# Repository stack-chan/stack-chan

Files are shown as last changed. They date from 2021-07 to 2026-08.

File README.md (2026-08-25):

# Stack-chan




[日本語](./README_ja.md)

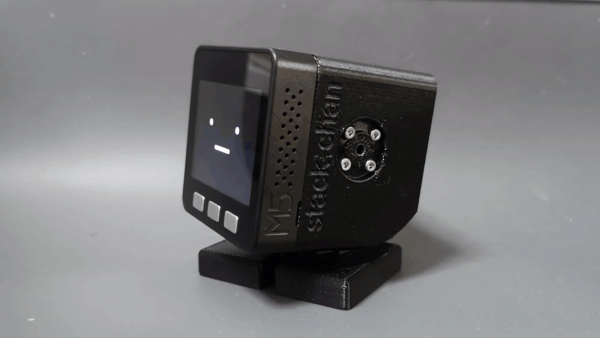
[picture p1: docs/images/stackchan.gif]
stackchan


Stack-chan is an open-source, JavaScript-driven, super-kawaii robot built with M5Stack.

This repository provides firmware with M5StackChan CoreS3 as its standard configuration, user applications called MODs, browser development tools, cases, and schematics.

- Video (with English subtitles): https://youtu.be/fZb_mF08xV0
- Official hashtag: [`#stackchan` | `#ｽﾀｯｸﾁｬﾝ` (JP)](https://twitter.com/search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)

## Getting started

If this is your first Stack-chan, start with a preassembled M5StackChan and the browser tools.

### 1. Get an M5StackChan

The standard M5StackChan AI Desktop Robot (K151) package is enough to get started.
The joystick remote controller is optional.

- Worldwide: [M5Stack Official Store](https://shop.m5stack.com/products/stackchan-kawaii-co-created-open-source-ai-desktop-robot)
- Japan: [M5StackChan](https://ssci.to/11129)
- Japan: [M5StackChan with joystick remote controller](https://ssci.to/11131)

### 2. Flash the firmware

Connect M5StackChan to a computer with a data-capable USB cable, then open the [Web firmware installer](https://stack-chan.github.io/stack-chan/web/flash/) in Chrome or Edge.
Select "M5StackChan CoreS3" as the device.
You do not need to install the Moddable SDK or ESP-IDF.

> [!IMPORTANT]
> Flashing this repository's firmware replaces the factory firmware supplied by M5Stack.
> To restore it, follow the restore procedure in the [M5Stack product documentation](https://docs.m5stack.com/en/StackChan) and use M5Burner.

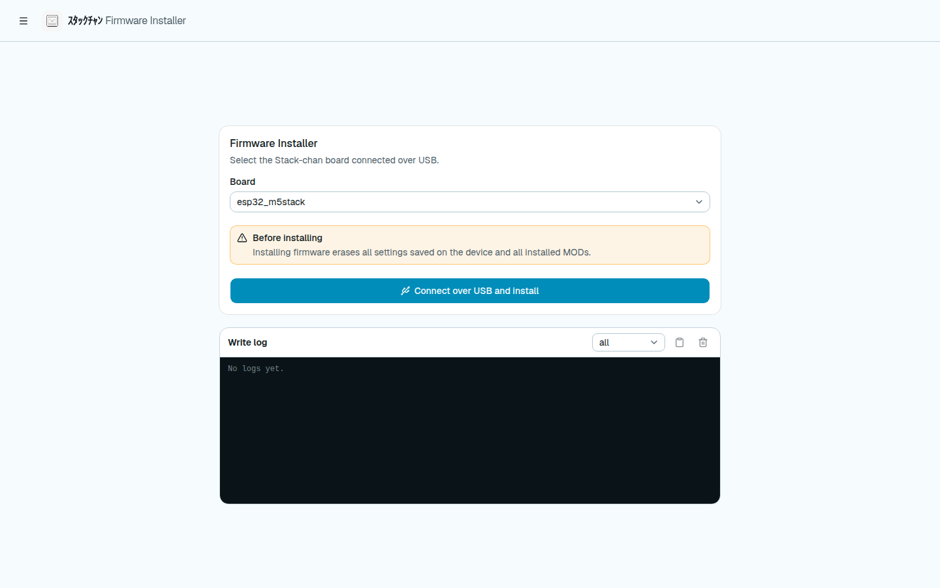
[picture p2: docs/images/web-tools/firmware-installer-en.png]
Web firmware installer


### 3. Try a MOD

Find published MODs and mini apps in the [MOD Gallery](https://stack-chan.github.io/stack-chan/web/mod-gallery/).
Choose a MOD, then run it in the simulator or install it on a device.
Block-based samples can be opened directly in the block editor and changed.

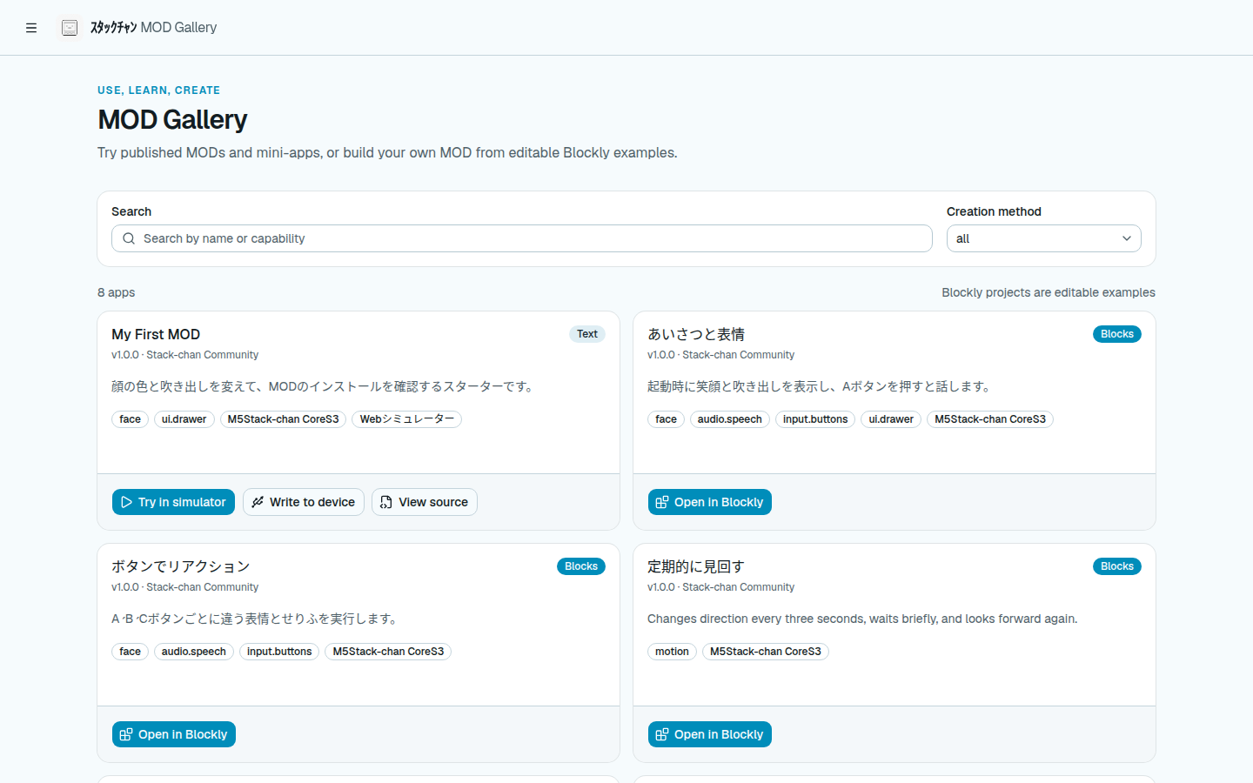
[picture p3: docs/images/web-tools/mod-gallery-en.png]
MOD Gallery


## Browser tools

Use the [Stack-chan browser tools](https://stack-chan.github.io/stack-chan/web/) to set up a device, change its preferences, and create MODs in a browser.

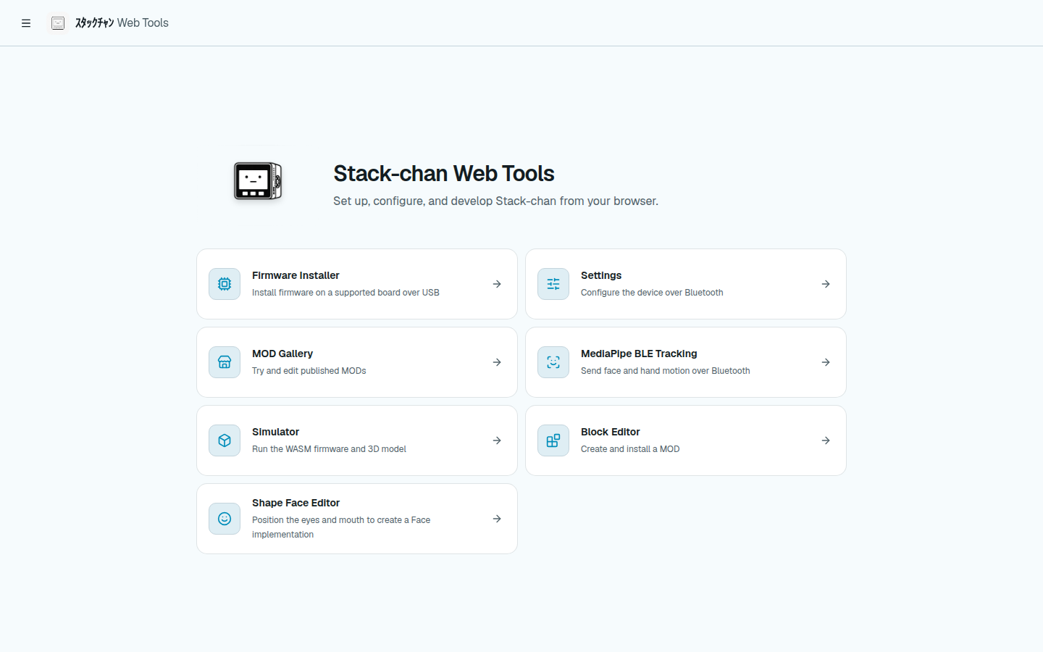
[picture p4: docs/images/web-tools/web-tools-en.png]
Stack-chan browser tools home screen


| Tool | Purpose |
| --- | --- |
| [Firmware installer](https://stack-chan.github.io/stack-chan/web/flash/) | Flash firmware to a supported M5Stack over USB |
| [Preferences](https://stack-chan.github.io/stack-chan/web/preference/) | Change Wi-Fi and device preferences over BLE |
| [MOD Gallery](https://stack-chan.github.io/stack-chan/web/mod-gallery/) | Find, try, and install published MODs |
| [Block editor](https://stack-chan.github.io/stack-chan/web/editor/) | Create MODs with Blockly and run them in the simulator or on a device |
| [Shape face editor](https://stack-chan.github.io/stack-chan/web/face-editor/) | Arrange eyes and a mouth to create a custom Face |
| [Simulator](https://stack-chan.github.io/stack-chan/web/simulator/) | Run MODs with the WebAssembly firmware and a 3D model |
| [MediaPipe BLE tracking](https://stack-chan.github.io/stack-chan/web/mediapipe/) | Send tracked face and hand movement over BLE |

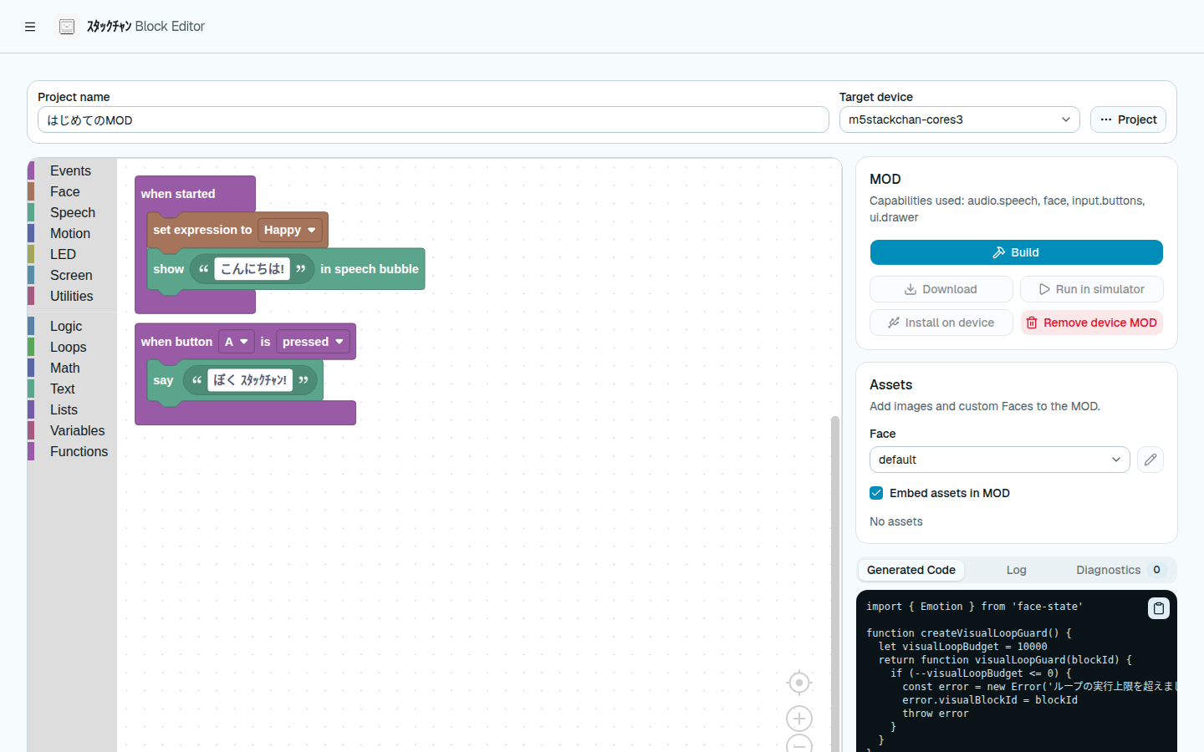
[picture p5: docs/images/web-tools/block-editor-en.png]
Block editor


## Supported hardware

The distributed firmware supports M5Stack, M5Stack Core2, M5Stack CoreS3, and M5StackChan CoreS3.
M5StackChan CoreS3 is the standard configuration and the target used for physical-device release validation.

Firmware for Stack-chan RT and Takao Core2 + SG90 can be built from source.
See the [firmware guide](./firmware/README.md) for target-specific commands and constraints.

To build the hardware yourself, see the [case guide](./case/README.md) for parts and assembly instructions.
See the [schematics](./schematics/README.md) for board information.

## Repository contents

- [firmware](./firmware/): Host firmware, modules, MODs, and development scripts
- [web](./web/): Firmware installer, preferences, editors, Gallery, and simulator
- [case](./case/): Case models for 3D printing
- [schematics](./schematics/): Schematics and board layouts
- [docs](./docs/): Roadmap, specifications, operations guides, and release notes

## Development

- [Firmware development](./firmware/README.md)
- [MOD development](./firmware/mods/README.md)
- [Firmware API](./firmware/docs/api.md)
- [Contribution guide](./CONTRIBUTING.md)
- [Latest release](https://github.com/stack-chan/stack-chan/releases/latest)
- [Development roadmap](./docs/ROADMAP.md)

## Contributing

Feature requests, bug reports, and pull requests are welcome.
Read the [contribution guide](./CONTRIBUTING.md), or open an [issue](https://github.com/stack-chan/stack-chan/issues).

To support the project financially, visit the [GitHub Sponsors page](https://github.com/sponsors/meganetaaan/).

## License

The resources in this repository are distributed under the Apache License 2.0.
See [LICENSE](./LICENSE).

## BibTeX

```bibtex
@misc{stackchan,
  author       = {Shinya Ishikawa and the Stack-chan community},
  title        = {Stack-chan: A JavaScript-driven Super-kawaii Robot},
  year         = {2021},
  howpublished = {\url{https://github.com/stack-chan/stack-chan}},
  note         = {Open-source hardware and software.},
}
```

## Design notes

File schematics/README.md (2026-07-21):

# Stack-chan schematics

[日本語](./README_ja.md)

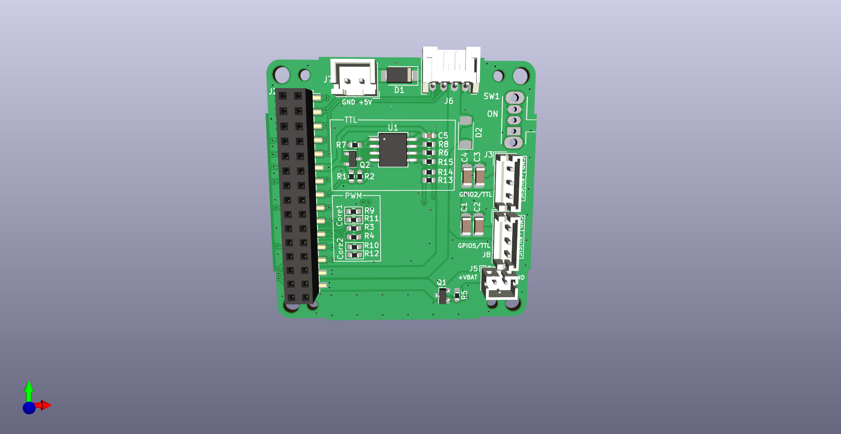
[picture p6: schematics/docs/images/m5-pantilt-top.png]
board top

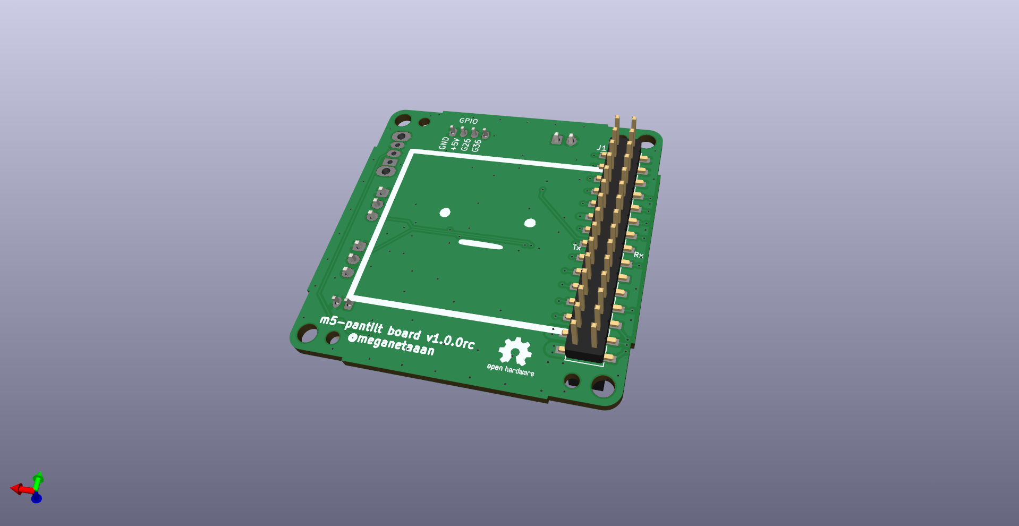
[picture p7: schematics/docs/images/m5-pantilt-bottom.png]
board bottom

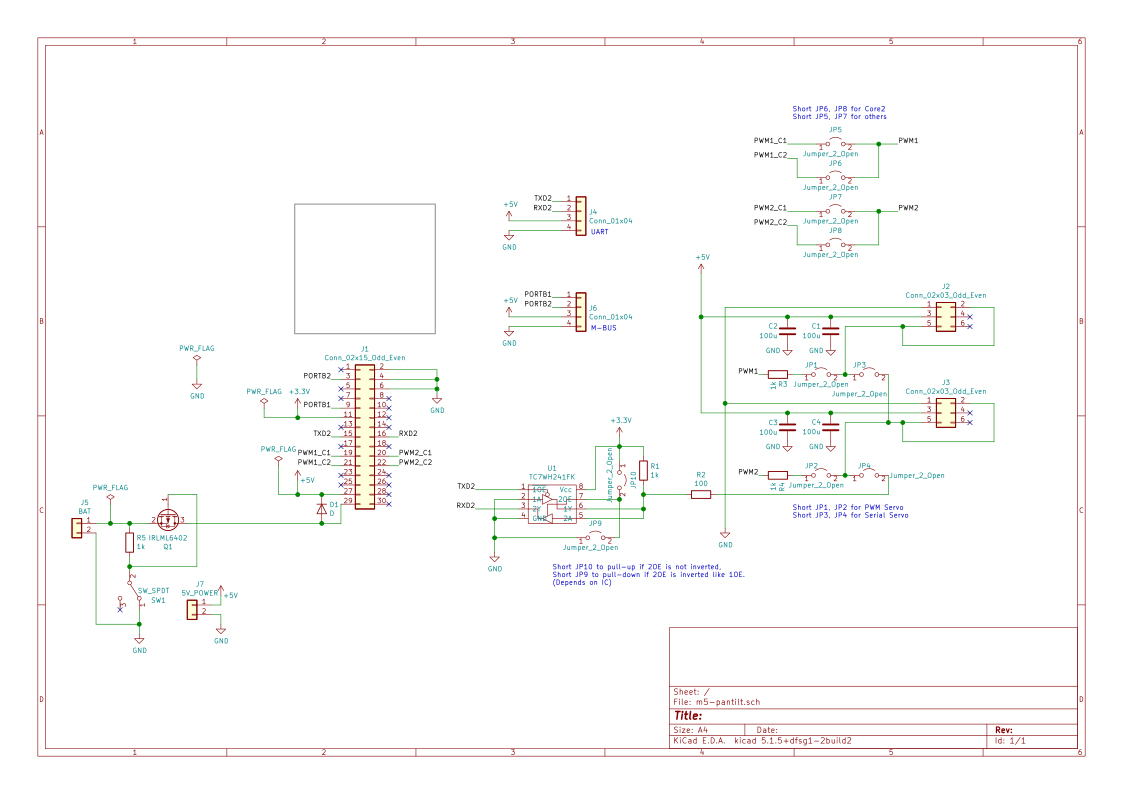
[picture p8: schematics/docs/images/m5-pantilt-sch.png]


## Feature

* Drive two servos
  * PWM * 2ch or
  * Serial * 2ch
* M5Unit PortB
* External 5V Power Supply
* Battery, which can be charged through M5Stack.
* (Optional) Power switch

## Parts list

See the parts list on our GitHub Pages (under construction)

### Which type of servo should I use?

#### PWM (SG90)

**Pros**: Low cost
* Very low cost (~500yen), easy to find.
* PortC (serial communication) is available for users.

**Cons**: Difficult to control and having a (small) safety risk.
* Difficult to change its angle smoothly.
* Inrush current is high and may cause the M5Stack to power down in rare cases. SG90 possibly get very hot and may emit smoke when overloaded, such as when the angle exceeds the physical limits of the Stack-chan.
* Cannot control torque ON/OFF. Twisting the Stack-chan's head while the torque is ON may result in servo damage.

#### Serial (RS304MD)

**Pros**: High functionality
* Complex control such as speed limit is possible. Since the current servo angle can be read, we can make rich functions such as changing the action according to the direction of the stuck-chan's face.

**Cons**: High cost and having a bit large size.
* It is relatively expensive (~3,000 yen)
* Users cannot use PortC. 
* Because RS304MD is a bit larger than SG90, it sticks out slightly behind the body.

## SMD PCB Manufacturing

You can place an order for SMD (Surface Mount Device) PCBs with PCB manufacturers like JLCPCB using the following files (links to be added):

- Gerber Files
- BOM (Bill of Materials)
- CPL (Component Placement List)

(A guide on how to place an order will be posted soon.)

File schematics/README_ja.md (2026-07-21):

# ｽﾀｯｸﾁｬﾝ 基板

[English](./README.md)

基板の写真は最新のバージョンと異なる場合があります。

board top
board bottom
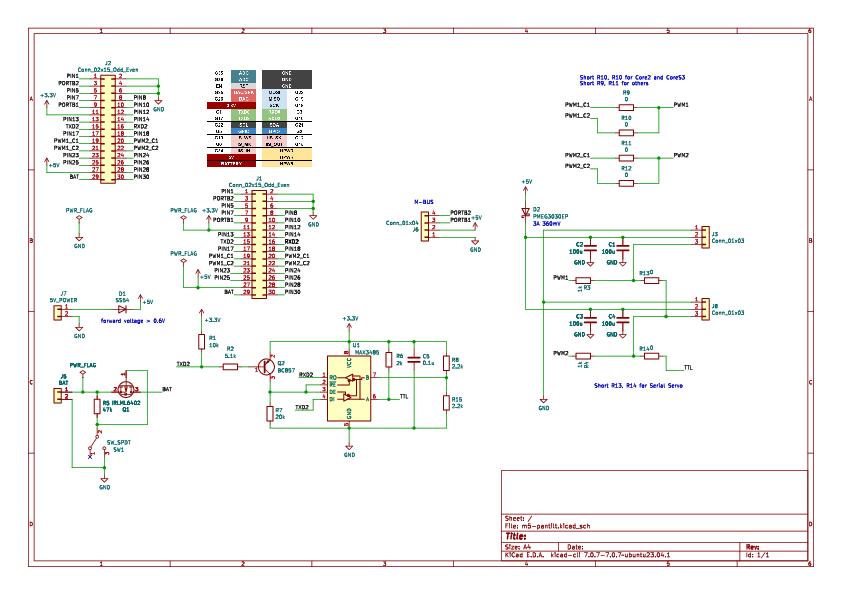
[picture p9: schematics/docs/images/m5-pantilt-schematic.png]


## 機能

* 2つのサーボを駆動
  * PWM * 2chまたは
  * TTL * 2ch
* M5Unitのポート（PortB）を搭載
* 電池 (M5Stackからの充電に対応)
* 外部からの5V給電
* (オプション) 電源スイッチ

## パーツリスト

ｽﾀｯｸﾁｬﾝのGitHub Pagesを参照してください（リンク追加予定）。

### PWMとシリアルサーボのどちらが良いか

#### PWMサーボ (SG90)

**Pros**: 低コスト
* 低コスト (~500円)で入手性が高いです。
* PortC (シリアル通信) が利用可能です。

**Cons**: 制御が難しい & 若干の安全性リスク有り
* サーボの角度をスムーズに変化させることが難しいです。
* 突入電流が大きく、まれにM5Stackの電源が落ちることがあります。例えば、ｽﾀｯｸﾁｬﾝの物理的な拘束を超えた角度司令を与えたときなどは、SG90が発熱したり発煙したりする場合があります。
* トルクのON/OFFの制御ができません。トルクがONの状態でｽﾀｯｸﾁｬﾝの頭をひねるとサーボが破損する場合があります。

#### シリアルサーボ (RS304MD)

**Pros**: 高機能
* 角速度制限などの複雑な制御が可能です。また、現在の角度情報を読み取れるので、ｽﾀｯｸﾁｬﾝの顔の向きに合わせて動作を変えるなど、高度な機能を実現できます。

**Cons**: 高コスト & サイズが大きい
* 高コスト (~3000円)
* RS304MDはSG90より一回り大きいので、サーボが本体から少し飛び出た格好になります。

## SMD基板の製造

下記のファイル（リンクを追加予定）を使って、JLCPCB等のPCBメーカーにSMD（表面実装）基板の発注が可能です。

- ガーバーファイル
- BOM（部品表）
- CPL（部品配置）

（発注方法のガイドを掲載予定）

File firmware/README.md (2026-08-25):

# Stack-chan firmware

[日本語](./README_ja.md)

## About this firmware

The M5Stack factory firmware preinstalled on M5StackChan and the Stack-chan firmware in this repository are separate firmware implementations.
Use the [latest release](https://github.com/stack-chan/stack-chan/releases/latest) when you need a stable environment.
The default `develop` branch may change internal structures and APIs while preparing the next release.

AI Stack-chan is a separate Arduino-based application developed primarily by @robo8080.
If you are looking for AI Stack-chan, see [AI_StackChan2](https://github.com/robo8080/AI_StackChan2).

If you are comfortable with the Arduino IDE and use PWM servos, [stack-chan-tester](https://github.com/mongonta0716/stack-chan-tester) by @mongonta0716 is another option.

## Try it in a browser

For a first trial, the [Stack-chan browser tools](https://stack-chan.github.io/stack-chan/web/) let you start without installing a local development environment.

1. Connect M5StackChan to a computer with a data-capable USB cable.
2. Open the [Web firmware installer](https://stack-chan.github.io/stack-chan/web/flash/) in Chrome or Edge, select "M5StackChan CoreS3," and install the firmware.
3. Choose a MOD from the [MOD Gallery](https://stack-chan.github.io/stack-chan/web/mod-gallery/) and try it in the simulator or on the device.

> [!IMPORTANT]
> Flashing this firmware replaces the factory firmware supplied by M5Stack.
> To restore it, follow the restore procedure in the [M5Stack product documentation](https://docs.m5stack.com/en/StackChan) and use M5Burner.

Web firmware installer

## Start local development

The standard firmware target is M5StackChan CoreS3.
To change the source code, run these commands from the `firmware` directory:

```console
npm i
npm run setup
npm run setup -- --device=esp32
npm run doctor
npm run flash
```

`npm run flash` builds and flashes the standard host.
For Stack-chan RT or Takao Core2 + SG90, use `npm run flash:stackchan_rt` or `npm run flash:takao_core2_sg90`.
When updating only a MOD, pass its manifest: `npm run mod -- mods/examples/look_around/manifest.json`.
The command builds a MOD archive, discovers the device's `xs` partition, and writes it directly with `esptool`.
Because it does not use the xsbug install channel, the installed host can be either a debug or release build.

## Features

- Develop MODs in JavaScript or TypeScript.
- Update a MOD quickly without rebuilding the host because the host program and MODs are separate.
- Use capability-oriented context APIs for faces, motion, input, audio, camera, and connectivity.
- Run Stack-chan with multiple motor configurations, including Feetech, FUTABA, DYNAMIXEL, and PWM servos.
- Generate speech through Stack-chan Voice, VOICEVOX, ElevenLabs, or OpenAI.
- Access firmware installation, BLE preferences, the MOD Gallery, the block editor, the face editor, and the WebAssembly simulator from a browser.
- Use the firmware and Web UI in Japanese, English, or Simplified Chinese.

## Build output

Use the repository npm scripts for firmware development.
They manage the Moddable output directory and keep host, MOD, and test build artifacts under `firmware/dist/`:

- Programs are written under `firmware/dist/bin/` and intermediate files under `firmware/dist/tmp/`.
- The host application name is `stack-chan-host`.
- `npm run clean` removes all generated files under `firmware/dist/`.
- Do not pass a custom `-o` or invoke `mcconfig`, `mcrun`, or `mcpack` directly when using the repository workflow.
- `npm run bundle` builds every release target under `firmware/dist/` and stages validated target artifacts in `firmware/dist/bundle-targets/`.
  It writes the assembled directory and ZIP under `firmware/host/app/`.
- Use the named `build:release:<target>` scripts for individual release builds.
  CI uses the same scripts before `bundle:package` assembles their artifacts.

See [Building and Writing Programs](docs/flashing-firmware.md) for target-specific commands and detailed output paths.

## Directory structure

- [host](./host/): Host application and firmware modules.
- [mods](./mods/): Source code of mods.
- [scripts](./scripts/): Development scripts for builds, validation, tests, and speech generation.
- [typings](./typings/): TypeScript definitions that supplement some Moddable SDK modules and Stack-chan-specific APIs.
- `dist/`: Generated firmware programs and intermediate build files.
  Build scripts manage this directory, and Git ignores it.

## Documents

### Use the browser tools

- [Browser tools](https://stack-chan.github.io/stack-chan/web/)
- [Flash firmware from a browser](docs/flashing-firmware-web.md)
- [Change preferences from a browser](docs/setting-preferences-web.md)
- [MOD Gallery](https://stack-chan.github.io/stack-chan/web/mod-gallery/)

### Develop locally

- [Set up the development environment](docs/getting-started.md)
- [Build and flash programs](docs/flashing-firmware.md)
- [API](docs/api.md)
- [MODs](mods/README.md)
- [Localization](docs/localization.md)
- [Mini apps (experimental, Japanese)](docs/mini-apps_ja.md)
- [v1.1.0 release notes](../docs/release-notes/v1.1.0.md)
- [v1.0.0 release notes](../docs/release-notes/v1.0.0.md)

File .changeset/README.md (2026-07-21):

# Changesets Foundation

This directory stores pending release notes for user-visible firmware and web changes.

Current scope:

- Track the release base branch as `develop`
- Review and consume pending Changesets on a frozen release branch
- Publish validated firmware assets from stable `vX.Y.Z` tags using `docs/release-notes/vX.Y.Z.md`

Package version bumps and the curated release note remain explicit release-branch changes. Future work can automate release pull request creation and changelog generation.

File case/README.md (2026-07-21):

# Stack-chan case v0

[日本語](./README_ja.md)

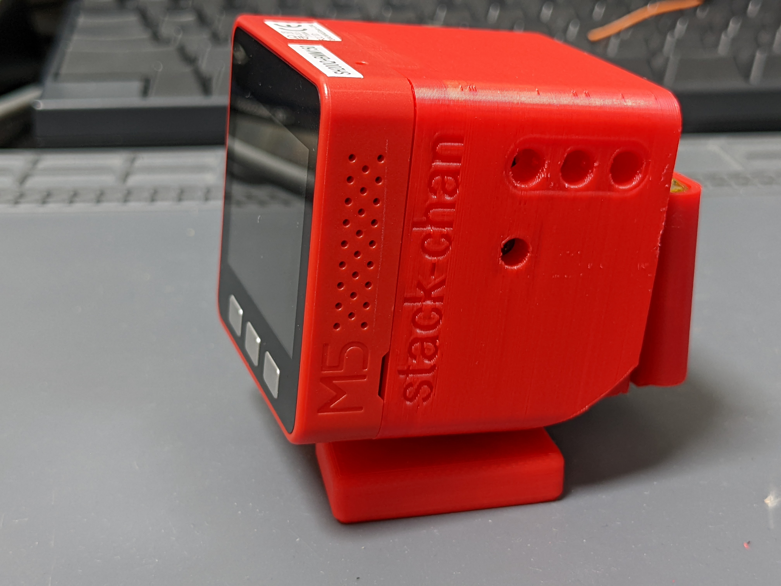
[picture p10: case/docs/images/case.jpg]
case

case_inside

Currently the [case data](https://a360.co/3gcw960) is developed with Fusion360.

## The case is transitioning to the new specification (v1.0)

We are making a new case with improved compatibility.

- Case v0 (this document)
  - PCB: [`v0.2.1`](https://github.com/stack-chan/stack-chan/tree/v0.2.1/schematics)
  - Servo motors: RX30X, SCS0009, SG90
- [Case v1.0](./v1/dynamixel.md)
  - PCB: [`v1.0`](../schematics/)
  - Servo motors: XL330 (more to be added over time)

__For the case with the latest specifications, please refer to the [Stack-chan case v1.0 document](./v1/dynamixel.md)__

## Editing

You can import and edit STEP files in each directory using any CAD software.

## 3D Printing

You can print STL files in each directory.
The recommended orientation is below.

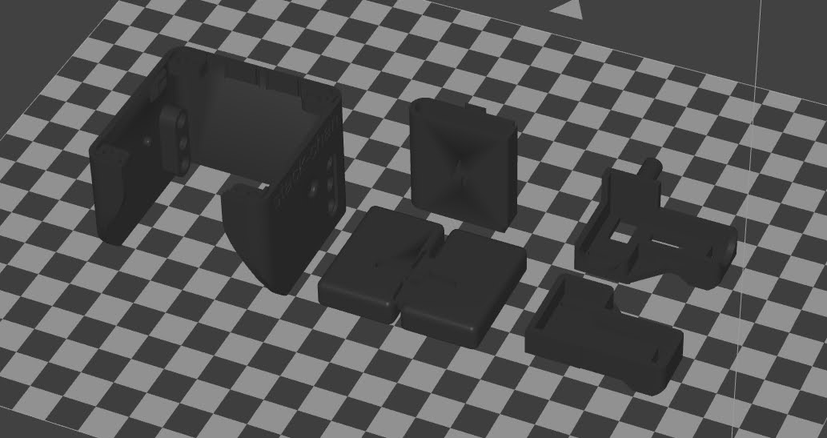
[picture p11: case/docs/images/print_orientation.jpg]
print orientation


## Assembly

### Parts

* 3D-printed cases
  * Shell
  * Feet
  * Bracket
  * Battery backpack
* M5Stack Core Basic/Gray/Go/Fire
* [Stack-chan board](../schematics/README.md)
* Two servos
  * Currently available on:
    * [RS30X series(TTL version)](https://www.vstone.co.jp/robotshop/index.php?main_page=product_info&products_id=2685) serial servo
    * [SCS0009(TTL version)](https://www.switch-science.com/catalog/8042/) serial servo
    * [SG-90 pwm servo](https://akizukidenshi.com/catalog/g/gM-08761/)
* 3.7V Battery with PH 2-pin cable
  * Tested on:
    * [lithium polymer 400mAh battery](https://www.sengoku.co.jp/mod/sgk_cart/detail.php?code=EEHD-4YZL))
    * [lithium polymer 640mAh battery](https://www.sengoku.co.jp/mod/sgk_cart/detail.php?code=EEHD-5GHY))
* Screws
  * M2 4mm * 4pcs
  * M2 8mm * 2pcs
  * (Optional) M3 15mm * 2本

### Serial Servo Setup

Serial servos share a signal line. It's necessary to specify ID for controlling each servo.
Therefore, different IDs must be assigned in advance.

- ID1: Foot side (left-right rotation, pan axis)
- ID2: Face side (vertical rotation, tilt axis)

The serial servo driver has a command `flashId` to rewrite IDs](https://github.com/meganetaaan/moddable-scservo/blob/71292b9358353837a74ecea387cd3265a 610479f/src/scservo.ts#L274). A servo configuration tool using this command is under development.

### About the angle of the servo

The angle of the servo mounting should be as follows.

- The center of the movable range is the reference angle (the angle when the stack chan faces forward).
- Install the servo so that the convex of the cross-shaped servo horn is aligned with the reference angle.
- If the servo is installed in the wrong direction, it will interfere with the stack chamber housing and will not operate properly.
  - We recommend that you check the operation of the servo by writing the firmware once before fixing the servo to the case.
- The movable range and reference angle are different for each servo type (see the following table).

|Servo |Movable range |Reference angle |
|:---|:---|:---|
|SG-90 |0~180 degrees |90 degrees |
|RS30X |-150~150 degrees |0 degrees |
|SCS0009|0~200 degrees |100 degrees |

### Set up SCS0009 with GUI

Set up the following settings using Feetech's official GUI tool.

* Change the ID of the servo
* Change the angle of the servo to the reference angle

In addition to the SCS0009, the following items are required.

* [URT1](https://www.switch-science.com/catalog/7490/)
* 6-9V power supply

* Download the GUI debugging tools from [Feetech's repository on gitee](https://gitee.com/ftservo/fddebug).
* Connect URT1
  * "DC6V-9V"...Power supply
  * "USB"...PC via microUSB cable
  * "G V1 S"...SCS0009 (Connecting multiple servos with the same ID will not work properly)
* Open `FD.exe`
* Select the COM port that URT1 is connected to, and select "Connect" without changing other values from default.
* Select "Scan"
* Select the servo connected to the URT1 as shown in the lower left corner of the screen.

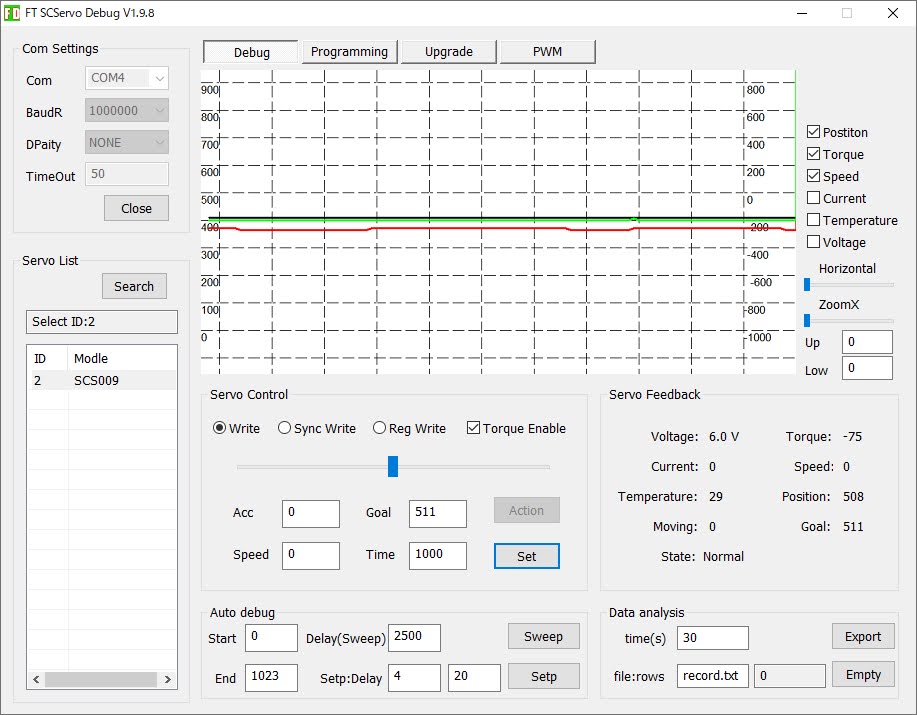
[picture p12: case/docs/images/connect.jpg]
Connection


* Set the value of "Goal" to 511 and select "Set"
  * The servo rotate to the reference angle
* If you change the servo's ID, Open the "Programming" tab
* Select the "ID" row, change the value and select "Save".
  * The ID is rewritten.

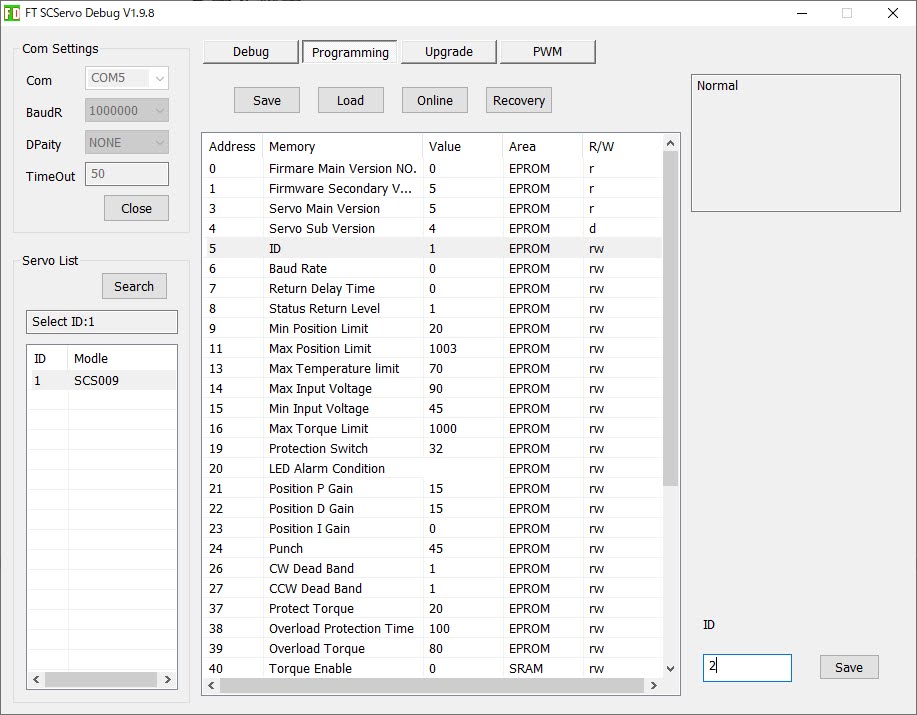
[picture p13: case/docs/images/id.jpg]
ID setting


__Caution: Do not use "Recovery" from the GUI. There are issues that the servo does not work properly after recovery (confirmed in FD v1.9.8.1 and v1.9.8.2)__.
If you choose "Recovery" and the servo stop working, try the following recovery method.

- [How to restore (JP)](https://drive.google.com/file/d/1AzPkGkHen-hhfPnCzJCY6UJheLU1gktv/view)

### How to Assemble

(Here are the steps with RS304MD servo. SG-90 and SCS0009 is similar to them)

#### Bracket and Battery backpack

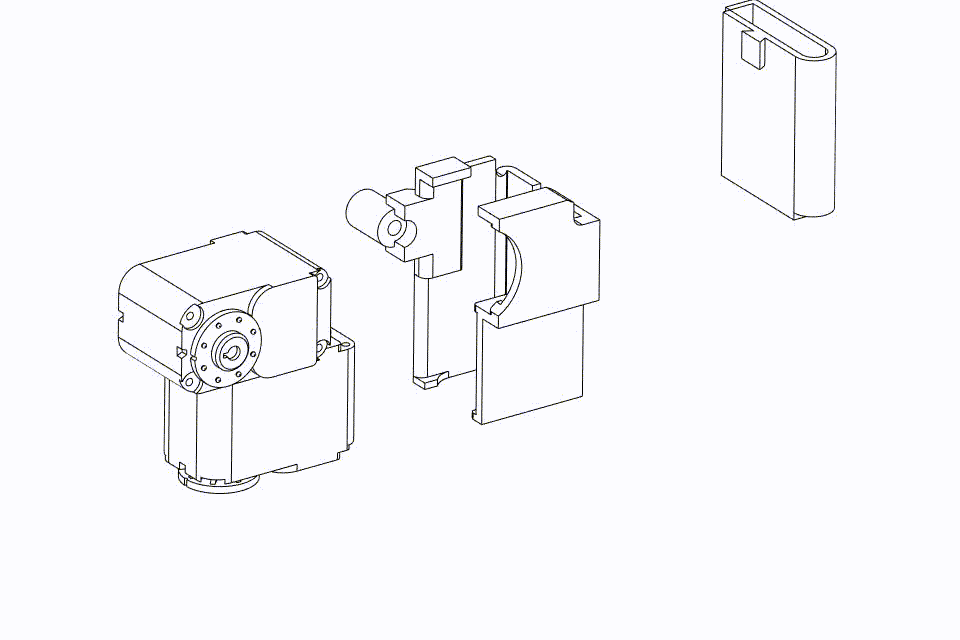
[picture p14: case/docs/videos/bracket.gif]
step1


* Snap two servos into the bracket.
* Insert battery into the backpack.
* Insert the battery pack into the bracket by hooking the claws.

#### Shell and Feet

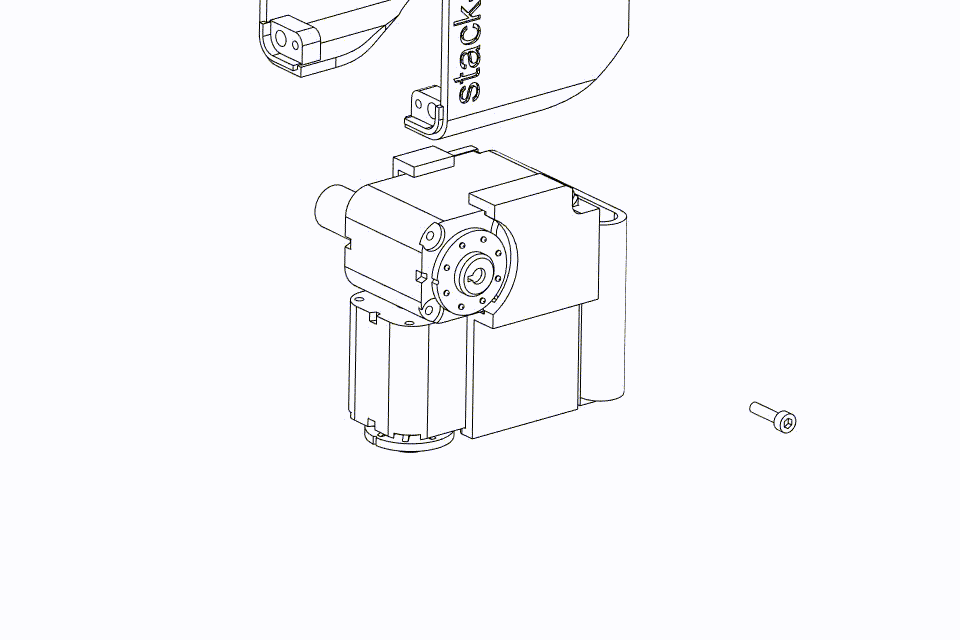
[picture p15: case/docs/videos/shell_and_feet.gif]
step2


* Fix feet and shell with screws(M2-8mm * 1pc for each of them).

#### M5Stack and board

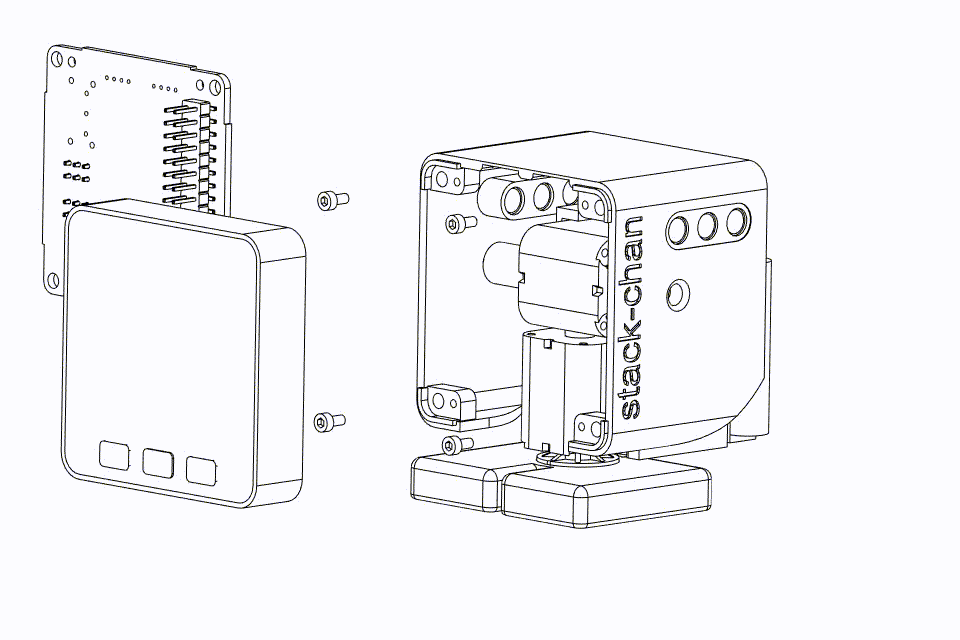
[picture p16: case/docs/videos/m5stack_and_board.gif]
step3


* Connect servo and battery cables to the board. Double check the direction of each connector is correct.
  * For serial servos, the servo with ID: 1 is for the foot side (pan axis) and the servo with ID: 2 is for the face side (tilt axis).

For SCS0009, The signal line (white cable) is connected to write the pin.

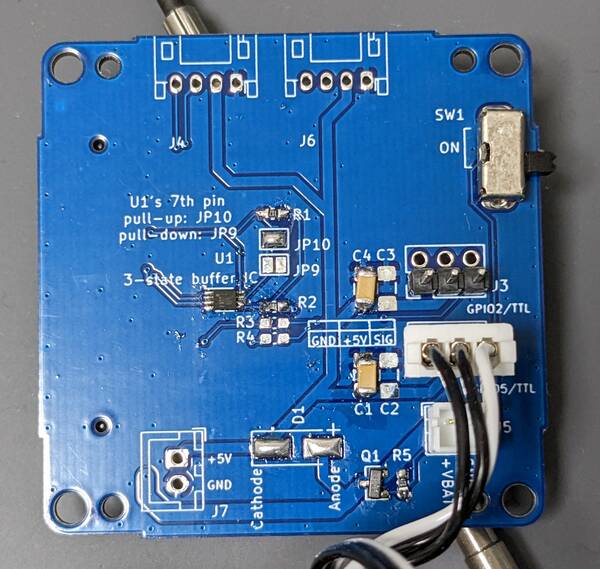
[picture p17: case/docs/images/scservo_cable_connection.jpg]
SCS0009 connection


* Fix the board on the robot with screws(M2-4mm * 4pcs)
* Stack M5Stack on the robot.
* If you want to fix the M5Stack, use the two holes below to screw(M3-15mm * 2pcs) it in place.

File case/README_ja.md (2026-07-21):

# ｽﾀｯｸﾁｬﾝ ケース v0

[English](./README.md)

case
case_inside

現在、[ケースデータ](https://a360.co/3gcw960)はFusion360で作成しています。

## ケースは新しい仕様（v1.0）に移行中です

より互換性を高めた新しいケースに移行中です。

- ケース v0（このドキュメント）
  - 基板: [`v0.2.1`](https://github.com/stack-chan/stack-chan/tree/v0.2.1/schematics)
  - 対応するサーボモータ: RX30X, SCS0009, SG90
- [ケース v1.0](./v1/dynamixel_ja.md)
  - 基板: [`v1.0`](../schematics/)
  - 対応するサーボモータ: XL330（随時追加予定）

__最新仕様のケースは[ｽﾀｯｸﾁｬﾝ ケース v1.0のドキュメント](./v1/dynamixel_ja.md)を参照してください__

## 編集

各ディレクトリのSTEPファイルをCADでインポートすると編集できます。

## 3Dプリント

各ディレクトリのSTLファイルを使って印刷ができます。
印刷の向きは次図のようにすると、仕上がりがきれいです。

印刷向き

## 組み立て

### パーツ

* 3Dプリントしたケース
  * 外殻(Shell)
  * 足(Feet)
  * ブラケット(Bracket)
  * バッテリーケース(Battery backpack)
* M5Stack Core (Basic/Gray/Go/Fireのいずれか), またはCore2
* [Stack-chan 基板](../schematics/README.md)
* サーボモータ2つ
  * 現在次のモータで動作確認しています
    * [シリアルサーボ RS30Xシリーズ(TTL通信)](https://www.vstone.co.jp/robotshop/index.php?main_page=product_info&products_id=2685)
    * [シリアルサーボ SCS0009(TTL通信)](https://www.switch-science.com/catalog/8042/) serial servo
    * [PWMサーボ SG-90](https://akizukidenshi.com/catalog/g/gM-08761/)
* PH 2ピンのケーブル付きの3.7Vバッテリー
  * 以下で動作確認しています
    * [400mAhのリチウムポリマーバッテリー](https://www.sengoku.co.jp/mod/sgk_cart/detail.php?code=EEHD-4YZL)
    * [640mAhのリチウムポリマーバッテリー](https://www.sengoku.co.jp/mod/sgk_cart/detail.php?code=EEHD-5GHY))
* ねじ
  * M2 4mm * 4本
  * M2 8mm * 2本
  * （オプション）M3 15mm * 2本

### シリアルサーボの設定

シリアルサーボは通信線を共有しており、IDを指定して角度変更や取得、トルクのオンオフなどを切り替える仕組みです。
そのためあらかじめ異なるIDを割り当てておく必要があります。

- ID1: 足側（左右回転、パン軸）
- ID2: 顔側（上下回転、チルト軸）

シリアルサーボのドライバには[IDを書き換えるコマンド`flashId`があります](https://github.com/meganetaaan/moddable-scservo/blob/71292b9358353837a74ecea387cd3265a610479f/src/scservo.ts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)。
このコマンドを使うとｽﾀｯｸﾁｬﾝ基板のみでサーボのIDを設定できます。

### サーボの角度について

サーボの取り付け角度は次のようにします。

- 可動範囲の中央が基準角度（ｽﾀｯｸﾁｬﾝが正面を向くときの角度）になります。
- 基準角度に十字のサーボホーンの凸が合うように取り付けてください。
- サーボの取り付け向きが間違っている場合、ｽﾀｯｸﾁｬﾝの筐体と干渉して正しく動作しません。
  - サーボをケースに固定する前に、一度ファームウェアを書き込んでの動作確認をおすすめします。
- サーボの種類ごとに可動範囲と基準角度が異なります（次表参照）

|サーボ  |可動範囲 |基準角度 |
|:---|:---|:---|
|SG-90  |0~180度 |90度 |
|RS30X  |-150~150度|0度 |
|SCS0009|0~200度 |100度 |

### （参考）SCS0009をGUIでセットアップする

次の設定をFeetech公式のGUIツールを使って行います。

* サーボのIDを変更する
* サーボの角度を基準角度に変更する

SCS0009本体に加えて次のものが必要です。

* [URT1](https://www.switch-science.com/catalog/7490/)
* 6-9Vの電源

* GUIのデバッグツールを[gitee（中国版GitHub）のFeetechのリポジトリ](https://gitee.com/ftservo/fddebug)からダウンロードします。
* URT1を接続します
  * 「DC6V-9V」…電源
  * 「USB」…microUSBケーブルを介してPCに接続
  * 「G V1 S」…SCS0009を接続（同じIDのサーボを複数接続すると正しく動作しません）
* `FD.exe`を開きます
* URT1を接続したCOMポートを選択し、その他の値はデフォルトから変更せず「Connect」を選択します
* 「Scan」を選択します
* 左下に接続されたサーボが表示されるので選択します

接続

* 「Goal」の値を511にして「Set」を選択します
  * サーボが基準角度まで回転します
* IDを変更する場合「Programming」タブを開きます。
* 「ID」の行を選択し、値を変更して「Save」を選択します。
  * IDが書き換わります。

IDの変更

__注意：GUIから「Recovery」を選択するとサーボが正しく動作しなくなる事象が報告されています（FD v1.9.8.1とv1.9.8.2で確認）のでご注意ください__
動作しなくなった場合下記の復旧方法をお試しください。

- [復旧方法（日本語）](https://drive.google.com/file/d/1AzPkGkHen-hhfPnCzJCY6UJheLU1gktv/view)

### 組み立て方

(RS304MDを使った場合です。SG-90, SCS0009も似ています)

#### ブラケット

ステップ1

* サーボをブラケットに差し込みます。
  * シリアルサーボの場合、足側（左右回転）がID: 1のサーボ、顔側（上下回転）がID: 2のサーボになります。
* バッテリーをバッテリーケースに差し込みます。
* 爪を引っ掛けるようにしてバッテリーケースをブラケットに差し込みます。

#### 外殻と足

ステップ2

* ねじで足と外殻を固定します(それぞれM2-8mm * 1本)

#### M5Stackと基板

ステップ3

* サーボとバッテリーのケーブルを基板に接続します。コネクタの向きが正しいか確認してください。
  * シリアルサーボの場合、ID1のサーボが足側（パン軸）、ID2のサーボが顔側（チルト軸）になります。

SCS0009の場合、信号線（白いケーブル）が右側のピンに接続されます。

SCS0009の接続

* 基板をねじで固定します(M2-4mm * 4本)。
* M5Stackをロボットにスタックします。
* M5Stackを固定する場合、下側の2つの穴を使ってねじで固定します(M3-15mm * 2本)

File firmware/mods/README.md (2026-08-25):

# MODs and examples

[日本語](./README_ja.md)

A **MOD** is a user application that runs on the Stack-chan host firmware.

## Try a MOD

Find published MODs in the [MOD Gallery](https://stack-chan.github.io/stack-chan/web/mod-gallery/).
Search by name or capability, then run a MOD in the simulator or on a device.
You can change block-based MODs in the block editor.

When choosing a MOD, review the capabilities and supported targets shown on its card.
If the MOD uses an external service or network access, inspect the linked source code before installing it.
At installation time, the Gallery automatically checks the target chip, XS version, and firmware compatibility.

MOD Gallery

The [`examples`](./examples/) directory contains source code for learning APIs, testing, and local development.
Some examples are also published in the Gallery.
The Gallery and `examples` do not yet contain the same set of MODs, but they will be aligned over time.

## Create a MOD

### Create one in a browser

The [block editor](https://stack-chan.github.io/stack-chan/web/editor/) lets you assemble behavior with Blockly and build a MOD in the browser.
You can test the result in the [simulator](https://stack-chan.github.io/stack-chan/web/simulator/) and install it on a compatible device.
Follow the [block editor tutorial](https://stack-chan.github.io/stack-chan/web/editor/tutorial.html) to create a first project.

Block editor

### Create one from source

A MOD can be implemented as a JavaScript or TypeScript module.
TypeScript MODs use the public Stack-chan capability types and Moddable module specifiers.

To install a MOD from a local environment, specify its manifest from the `firmware` directory:

```console
npm run mod -- mods/examples/look_around/manifest.json
```

See [Build and flash programs](../docs/flashing-firmware.md) for setup, target-specific commands, and installation details.

## MOD runtime model

Installing a MOD makes the host run that MOD instead of its default behavior.
Button and screen behavior therefore depends on the installed MOD.

A MOD must be built for the target device and the XS version used by its host.
For the WASM host, load an `.xsb` or archive built with a target that supports TypeScript, such as `lin`.

Add localized UI text as described in [Firmware localization](../docs/localization.md) through `context.i18n`.
To add a Piu UI while retaining the face screen and host AppBar, use the experimental [mini-app framework (Japanese)](../docs/mini-apps_ja.md).

## Representative source examples

| Example | What it demonstrates |
| --- | --- |
| [`look_around`](./examples/look_around/) | Minimal head movement through the motion API |
| [`localized_drawer`](./examples/localized_drawer/) | Localized UI through `context.i18n` |
| [`mini_app_sample`](./examples/mini_app_sample/) | A mini app that retains the face screen and AppBar |
| [`local_peer_hello`](./examples/local_peer_hello/) | Typed device-to-device messages without the internet |
| [`web_radio`](./examples/web_radio/) | Network audio playback on M5StackChan CoreS3 |
| [`m5stackchan_smoke`](./examples/m5stackchan_smoke/) | [M5StackChan CoreS3 servo-power and head LED checks](../docs/m5stackchan-cores3-smoke.md) |

## References

- [Build and flash programs](../docs/flashing-firmware.md)
- [Firmware API](../docs/api.md)
- [MOD package specification](../../docs/specs/stackchan-mod.md)
- [Localization](../docs/localization.md)
- [Mini apps (experimental, Japanese)](../docs/mini-apps_ja.md)

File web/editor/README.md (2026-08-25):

# Stack-chan Block Editor

Blockly-based MOD editor for Stack-chan. Everything runs client-side:

1. **Compose** — assemble Stack-chan behaviors (face, speech, motion, LED, buttons, timers) from blocks. The workspace generates a `mod.js` that exports `onContextCreated(robot)`.
2. **Build** — compile the MOD in the browser with the Moddable tools (`mcrun` → `xsc` → `xsa`) built to WebAssembly (`vendor/tools.js` + `vendor/tools.wasm`). The output is an XS archive (`mc.xsa`) containing xsb bytecode.
3. **Install** — into the [WASM simulator](../simulator/) (saved to IndexedDB, loaded at simulator launch), or onto a real device over WebSerial by flashing the archive into the device's `xs` flash partition with esptool-js. See [Installing to a real device](#installing-to-a-real-device).

The 「おしゃべり」 block calls `robot.audio.say(...)`. M5StackChan CoreS3
firmware and the WASM simulator both select the bundled offline
`stackchan-voice` engine, so the generated MOD uses the same synthesizer in the
browser and on the device.

The 「テンポ … で…を歌う」 block takes one score list. Each list item is a
`[pitch, beats, lyric]` triple; a rest is `['R', beats, '']`. The generated
helper validates the triples, converts the global BPM and beat counts to exact
milliseconds, romanizes each one-kana-mora lyric, and calls
`robot.audio.sing(...)` with raw `koe` notation. Singing is offered for the
M5StackChan CoreS3 and WASM simulator profiles, which both run the same bundled
engine.

## Files

| File | Role |
| --- | --- |
| `index.html` / `editor.mjs` / `editor.css` | Editor page, wiring, and styles |
| `blocks.mjs` | Block definitions, JavaScript generators, toolbox, `mod.js` assembly |
| `mod-builder.mjs` | Client-side build pipeline driving the WASM Moddable tools |
| `project-storage.mjs` | IndexedDB persistence and legacy localStorage migration |
| `esptool-installer.mjs` | WebSerial device install via esptool-js (flashes the `xs` partition) |
| `vendor/tools.js`, `vendor/tools.wasm` | Moddable SDK tools compiled with Emscripten |
| `vendor/esptool-js-0.5.7.bundle.mjs` | Pinned local WebSerial flasher bundle (Apache-2.0) |
| `*.test.mjs` | Node unit tests (`npm test` in `web/`) |

## Rebuilding `vendor/tools.wasm`

The tools binary embeds a Moddable SDK version (currently **9.0.0**, XS 17.8) and is generated with **Emscripten 5.0.1**. Rebuild it whenever either toolchain is updated:

```sh
cd firmware
source "$HOME/.local/share/xs-dev-export.sh"
source "/path/to/emsdk-5.0.1/emsdk_env.sh"
npm run build:editor-tools
```

Notes:

- `firmware/scripts/build-editor-tools.sh` owns the Emscripten flags and copies both generated files into `web/editor/vendor/`.
- The script rejects Moddable SDK or Emscripten versions that differ from the versions above.
- CI runs the same command and fails when regeneration changes either tracked vendor file.
- `ENVIRONMENT=web,node` keeps the module loadable from both the browser and the Node test runner.
- `mod-builder.mjs` writes `/moddable/tools/VERSION` into the virtual filesystem before running `mcrun`; when the binary disagrees it detects the mismatch warning and retries with the binary's version, so a version bump usually needs no code change.

## XS version compatibility

An XS archive only loads when its XS version is compatible with the engine that runs it (`fxMapArchive` checks `XS_MOD_COMPATIBLE ≤ archive ≤ engine`). Practically:

- **Simulator** — `web/simulator/mc.wasm` must be built from the same (or newer) SDK as `vendor/tools.wasm`. Rebuild with `npm run build:wasm` in `firmware/`.
- **Device** — the flashed Stack-chan firmware must be built from the same (or newer) SDK. A version mismatch is rejected when the firmware maps the archive.

The build status line in the editor shows the XS version of the produced archive (e.g. `XS 17.8.0`).

## Simulator install requirements

The simulator needs an `mc.js` that exports `_malloc` / `_free` and `HEAPU8` so the MOD archive can be copied into WASM memory and handed to `fxMainLaunch` (see `web/simulator/bridge.mjs`). The stock Moddable wasm makefile does not export these, so `firmware/scripts/build-wasm.sh` overrides `LINK_OPTIONS` at build time. If the simulator says “this WASM build has no MOD install hook yet”, rebuild it with `npm run build:wasm`.

## Installing to a real device

The **実機に書き込み (WebSerial)** button installs the MOD entirely from the browser by
flashing the archive into the device's `xs` flash partition with
[esptool-js](https://github.com/espressif/esptool-js) — the same proven WebSerial path
the [Flash page](../flash/) uses (esp-web-tools wraps esptool-js). A MOD is exactly the
bytes of `mc.xsa` written to the `xs` partition (type `0x40`, subtype `1`); the firmware
maps and runs it on the next boot. `esptool-installer.mjs` does it:

1. Enter the ROM bootloader (esptool-js resets into it; on native USB-serial-JTAG parts
   this does not re-enumerate USB, so the WebSerial port stays valid).
2. Read the partition table from the fixed `0x8000` offset and locate the `xs` partition.
   The offset differs per board (flash size / layout), so it is **not** hardcoded.
3. Write the archive to that offset (`flashSize/Mode/Freq: keep`, no full erase).
4. Reboot into the MOD over CDC control signals — no physical RESET button. esptool-js's
   own `after('hard_reset')` only pulses RTS and can leave DTR asserted, which on a native
   USB-serial-JTAG part maps to IO0 (boot select) and reboots back into the download ROM;
   `resetToRunApp()` drives IO0 high (DTR false) while pulsing EN (RTS), both set in one
   `setSignals` call, so the chip boots the app.

Why flash the partition instead of the xsbug debug channel: it is reliable and
board-agnostic, needs no debug build and no on-device trigger, and sidesteps the fragile
xsbug handshake on native USB-serial-JTAG parts (CoreS3).

Requirements:

- A browser with WebSerial (Chrome / Edge).
- The flashed Stack-chan firmware must be **8.3.x or 9.0.x**, and its XS version must be
  **≥ the archive's** (XS 17.8 here) — see [XS version compatibility](#xs-version-compatibility). No debug build needed.
- The `-p wasm` archive runs on the ESP32 device because `fxMapArchive` gates only on the
  XS version, skips the signature, and remaps symbols by name at install time — so the
  build platform need not match the device. Verified end-to-end on an M5Stack CoreS3
  (face + balloon appear after the auto-reboot).

esptool-js 0.5.7 is checked into `vendor/` with its Apache-2.0 license and loaded locally.
Its self-contained browser bundle inlines pako and the per-chip flasher stubs.
`check:editor-artifacts` verifies the SHA-384 digest against the reviewed npm artifact.

## Tests

```sh
cd web
npm test
```

`mod-builder.test.mjs` includes a real end-to-end compile through the WASM tools (no
network needed). `esptool-installer.test.mjs` covers partition-table parsing, `xs`
partition lookup across board layouts, and the install/flash sequence with a stubbed
loader.

## Project and learning guides

- The versioned authoring format and safety contract are defined in `docs/specs/visual-programming.md`.
- The Japanese 5-, 15-, and 30-minute walkthrough is in `TUTORIAL_ja.md`.
- Evaluation events can be exported from the chart button in the editor header.

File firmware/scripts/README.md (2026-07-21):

# TTS (Text-to-Speech) Auto-Generation Command Description

[日本語](./README_ja.md) | English

## generate-speech-google (for [Google Text-to-Speech](https://cloud.google.com/text-to-speech))

* Preparation  
    First, you need a Google account. If you don't have one, please create one.  
    Refer to Google's [authentication start guide](https://cloud.google.com/docs/authentication/getting-started) to create a project and service account, and create and obtain a key in JSON format. Also, search for "Cloud Text-to-Speech API" in the search bar, open it, and enable it.  
    Copy the acquired key file to the `stack-chan\firmware\scripts` directory and rename it to `key.json`.  
    The usage fee is free up to 1 million characters per month. If you use more than that, it will be $16 for every additional 1 million characters. New users will receive $300 in free credit.  
    For more information, please refer to the [Text-to-Speech documentation](https://cloud.google.com/text-to-speech).

* Unique options for generate-speech-google  
  * --voicename: Specify the text-to-speech voice.  
     The default is ja-JP-Wavenet-A (Japanese) or en-US-Wavenet-F (English).  
     Normally, it generates a speech file in Japanese. However, if the file name without the extension ends with "_en" or if you specify EN with the --lang option, it will be in English.  
     Corresponds to the parameters 'name' and 'languageCode' (generated from 'name').
  * --sample: Sampling rate.  
    The default is 44100 (44.1KHz). However, if you perform a pitch shift with pitch-shift.js, the final output file's sampling rate will always be 44.1KHz, regardless of the settings.
    Corresponds to the parameter 'sampleRateHertz'.
  * --speed: Text-to-speech speed.  
    The default is 0, which corresponds to the parameter 'speakingRate'.
  * --pitch: Pitch shift by Google TTS.  
    The default is 0, which corresponds to the parameter 'pitch'.  
    (The effect may not be very noticeable or the sound may be distorted, depending on the speech.)
  * --lang: Switch between default text-to-speech voices JA or EN.  
    Normally, JA or EN is identified by the end of the file name without the extension. However, you can use this option if you want to intentionally make an English input file be read in Japanese.
  * --shift: Pitch shift by pitch-shift.js.  
    Ranges from 0.5 (1 octave lower) to 2 (1 octave higher), with 1 being normal (Google TTS output as is).  
    If omitted, the value of 'SynthProps.shift' in the input file will be used. However, if it is also undefined, it will be 1.5.  
    Note that if this pitch shift is enabled, the output file's sampling rate will always be 44.1KHz, regardless of the Google TTS settings.

* Common options  
  * --input: Input file name.  
    If omitted, it will be 'speeches.js' in the current directory if it exists.  
    If not, it will be './host/modules/audio/assets/sounds/speeches_ja.js' (assuming execution in the 'stack-chan/firmware' directory).
  * --output: Output directory.  
    If omitted, it will be the 'assets' directory under the directory where the input file is located, if it exists.  
    If there is no 'assets' directory, it will be the same directory as the input file.

* Example of execution  
    `~/stack-chan/firmware$ npm run generate-speech-google -- --input=./mods/examples/monologue/speeches_monologue.js --output=./mods/examples/monologue/assets`
    Note: When specifying options, add ' -- ' after the command as shown above.

## generate-speech-coqui (for [CoquiTTS](https://github.com/coqui-ai/TTS#readme))

* Preparation  
  You need to install CoquiTTS and start the TTS-Server.  
  Follow the [installation instructions](https://github.com/coqui-ai/TTS#install-tts) to install it. Since it is a Python module, you can install it with `pip install TTS`. However, it seems that it doesn't install well on Windows, so if you want to generate audio files on Windows, you will need to use a TTS-Server running on another Linux environment, etc., via the network.  
  Once the installation is complete, execute the following command to start the TTS-Server:  
  `$ tts-server --port 8080 --model_name tts_models/ja/kokoro/tacotron2-DDC`

* Unique options for generate-speech-coqui  
  * --host: Hostname or IP address of the host where the TTS-Server is running.  
    Usually, it is read from host/app/manifest_local.json, but if you specify it here, it will take precedence. You need to specify it in one of the two places.
  * --port: Port of the TTS-Server.  
    Usually, it is read from host/app/manifest_local.json, but if you specify it here, it will take precedence. You need to specify it in one of the two places.
  * --shift: Pitch shift by pitch-shift.js.  
    Ranges from 0.5 (1 octave lower) to 2 (1 octave higher), with 1 being normal (CoquiTTS output as is).  
    If omitted, the value of 'SynthProps.shift' in the input file will be used. However, if it is also undefined, it will be 1.5.  
    Note that if this pitch shift is enabled, the output file's sampling rate will be 44.1KHz (CoquiTTS itself outputs at 22.05KHz).

* Common options  
  * --input: Input file name.  
    If omitted, it will be 'speeches.js' in the current directory if it exists.  
    If not, it will be './host/modules/audio/assets/sounds/speeches_ja.js' (assuming execution in the 'stack-chan/firmware' directory).
  * --output: Output directory.  
    If omitted, it will be the 'assets' directory under the directory where the input file is located, if it exists.  
    If there is no 'assets' directory, it will be the same directory as the input file.

* Example of execution  
    `~/stack-chan/firmware$ npm run generate-speech-coqui -- --input=./mods/examples/monologue/speeches_monologue.js --output=./mods/examples/monologue/assets`
    Note: When specifying options, add ' -- ' after the command as shown above.

## generate-speech-voicevox  (For [VOICEVOX](https://voicevox.hiroshiba.jp/))

* Preparation  
    Download and install from the [VOICEVOX website](https://voicevox.hiroshiba.jp/) (Windows/MAC/Linux versions available)  
    Once the installation is complete, launch VOICEVOX (the engine running simultaneously will be used; there seems to be a [method to launch only the engine from the command line](https://qiita.com/yamanohappa/items/b75d069e3cb0708d8709))
* Unique options for generate-speech-voicevox  
  * --list Character list output  
    If no value is specified, a list of all characters will be displayed and then the process will exit  
    If a SpeakerId is specified, only the character with that Id will be displayed  
    To specify a character with the --speaker option, use the SpeakerId displayed here  
  * --host Hostname or IP address of the VOICEVOX engine  
    If omitted, the default is 127.0.0.1 when VOICEVOX is launched normally
  * --port Port number of the VOICEVOX engine  
    If omitted, the default is 50021 when VOICEVOX is launched normally  
  * --speaker Specify character  
    Specify the SpeakerId of the character you want to speak  
    If omitted, the default is SpeakerId:1 Zundamon (Amaama)  
  * --speed Speaking speed  
    Specify the speaking speed, ranging from 0.5 to 2. The default value when omitted is 1
  * --pitch Pitch  
    Adjust the pitch of the voice, ranging from -0.15 to 0.15. The default value when omitted is 0  
  * --intonation Intonation  
    Specify the strength of the voice intonation, ranging from 0 to 2. The default value when omitted is 1  
  * --sample Sampling rate  
    The sampling rate of the output audio file. The default value when omitted is 11025 (11.025KHz)  
* Common options
  * --input Input file name  
    If omitted, it will default to speeches.js in the current directory if present  
    If not present, it will default to ./host/modules/audio/assets/sounds/speeches_ja.js (assuming execution in the ~/stack-chan/firmware directory)
  * --output Output directory  
    If omitted, it will default to the assets directory under the input file's directory if it exists  
    If the assets directory does not exist, it will default to the same directory as the input file  
* Execution example
     ~/stack-chan/firmware$ npm run generate-speech-voicevox -- --input=./mods/examples/monologue/speeches_monologue.js --output=./mods/examples/monologue/assets
     ※ If you want to specify options, add ' -- ' after the command as shown above

## About License

Please check and use the terms of use for VOICEVOX and each voice library.

* VOICEVOX: Credit notation is required to indicate that VOICEVOX has been used.  
  For example, if you embed the voice of "Zundamon" in your app and distribute it, you need to include "VOICEVOX: Zundamon" on the app's introduction screen. ([Zundamon Voice Source Usage Agreement](https://zunko.jp/con_ongen_kiyaku.html))
  The details of the terms of use may vary depending on the voice library you use, so please check the [list of characters on the VICEVOX website](https://voicevox.hiroshiba.jp/#characters).

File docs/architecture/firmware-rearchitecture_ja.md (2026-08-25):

# ファームウェア再設計移行計画

作成日：2026-06-28

更新日：2026-06-30

対象：`firmware/host` と `firmware/mods` を中心とする Moddable ファームウェア。

この文書は、レビューで指摘した設計差分を、1本の移行計画として管理する。

移行後に見えた設計改善課題は [firmware-rearchitecture-followups_ja.md](./firmware-rearchitecture-followups_ja.md) にまとめる。

`[x]` は対応済み、`[ ]` は未対応を示す。

移行では後方互換を維持しない。

互換 API、互換ディレクトリ、互換アダプタを残す段階を作らない。

## 目標構成

移行後の `firmware/host` は、起動と合成、module、platform を分ける。

`firmware/mods` は、利用者向け MOD と sample MOD だけを置く。

製品既定動作は `firmware/host/app/default-behavior` に置く。

installed MOD が存在する場合、製品既定動作は実行しない。

`firmware/stackchan` は移行元としてだけ扱い、移行後の目標構成には残さない。

```text
firmware/
  mods/
    examples/
    <user-mod>/
  host/
    app/
      main.ts
      compose.ts
      manifest.json
      manifest_local.json
      default-behavior/
        behavior.ts
        manifest.json
        on-launch.ts
        on-context-created.ts
    modules/
      audio/
        manifest.json
        manifest.test.json
        manifest_wasm.json
        assets/
          sounds/
        wasm/
      camera/
        manifest.json
        manifest.test.json
      conversation/
        manifest.json
        manifest.test.json
        chat-audioio/
      connectivity/
        manifest.json
        manifest.test.json
        manifest_wasm.json
        ble/
        http-server/
        mcp-client/
        mcp-server/
        wasm/
      input/
        manifest.json
        manifest.test.json
      lighting/
        manifest.json
        manifest.test.json
      motion/
        manifest.json
        manifest.test.json
        protocols/
        servos/
      preferences/
        manifest.json
        manifest.test.json
      testing/
        manifest.json
      util/
        manifest.json
        manifest.test.json
      ui/
        manifest.json
        manifest.test.json
        assets/
          fonts/
          images/
        application/
          app-controller.ts
        views/
          main/
          splash/
          settings/
          camera-preview/
        components/
          app-bar/
          face/
          drawer/
          effects/
          bubble/
          status-bar/
        state/
          face-state.ts
    platforms/
      esp32/
      m5stackchan_cores3/
      lin/
      wasm/
```

矢印は、左の module が右の契約を使う向きを示す。

点線は、manifest による build-time の選択を示す。

```mermaid
flowchart TD
  App["host/app<br/>main, compose, default-behavior"]
  DefaultBehavior["host/app/default-behavior<br/>product fallback behavior"]
  PublicAPI["public capability API<br/>MOD に渡す契約"]
  Mods["mods<br/>examples, user mods"]

  UIApp["host/modules/ui/application"]
  UIViews["host/modules/ui/views"]
  UIComponents["host/modules/ui/components"]
  UIState["host/modules/ui/state"]
  UIAssets["host/modules/ui/assets"]

  Audio["host/modules/audio"]
  Camera["host/modules/camera"]
  Conversation["host/modules/conversation"]
  Connectivity["host/modules/connectivity"]
  Input["host/modules/input"]
  Lighting["host/modules/lighting"]
  Motion["host/modules/motion"]
  Preferences["host/modules/preferences"]
  Util["host/modules/util"]
  Testing["host/modules/testing"]

  Platforms["host/platforms<br/>esp32, m5stackchan_cores3, lin, wasm"]

  App -- "no installed MOD" --> DefaultBehavior
  App -- "installed MOD" --> Mods
  App --> PublicAPI
  DefaultBehavior --> PublicAPI
  App --> UIApp
  App --> Audio
  App --> Camera
  App --> Conversation
  App --> Connectivity
  App --> Input
  App --> Lighting
  App --> Motion
  App --> Preferences

  Mods --> PublicAPI
  PublicAPI --> UIApp
  PublicAPI --> Audio
  PublicAPI --> Conversation
  PublicAPI --> Motion
  PublicAPI --> Input
  PublicAPI --> Lighting
  PublicAPI --> Camera

  UIApp --> UIViews
  UIViews --> UIComponents
  UIViews --> UIState
  UIComponents --> UIState
  UIComponents --> UIAssets

  Conversation --> Audio
  Conversation --> Connectivity
  Connectivity --> Preferences
  Motion --> Util
  Input --> Util
  Camera --> Util
  Lighting --> Util

  Testing -. test helper .-> Audio
  Testing -. test helper .-> Conversation
  Testing -. test helper .-> Connectivity
  Testing -. test helper .-> Motion
  Testing -. test helper .-> UIApp

  Platforms -. manifest select .-> App
  Platforms -. manifest select .-> UIApp
  Platforms -. manifest select .-> Audio
  Platforms -. manifest select .-> Camera
  Platforms -. manifest select .-> Connectivity
  Platforms -. manifest select .-> Motion
```

## 移行計画

### 0. 方針固定

- [x] 対応済み：再設計後の本線では、旧 `Renderer` 契約を正規 API として扱わない。
- [x] 対応済み：後方互換用の adapter、deprecated API、旧 import alias を残さない方針に固定する。
- [x] 対応済み：UI は Piu `Application`、`Behavior`、`Template`、`Port`、`Skin`、`Texture` を直接使う方針に固定する。
- [x] 対応済み：移行後の merge 条件として、互換層と旧名の残存を `npm run check:legacy-names` で検出する手順を PR テンプレートへ入れる。
- [x] 対応済み：検索対象は `RendererCompat`、`renderer-`、`useRenderer`、`addDecorator`、`removeDecorator`、`robot.renderer`、`renderer.type`、`renderers-piu`、`firmware/tests` とする。

### 1. UI 層の移行

- [x] 対応済み：`firmware/stackchan/renderers-piu/renderer-compat.ts` を削除する。
- [x] 対応済み：`RendererCompat is a temporary adapter` の deprecated 警告が出る実装経路を削除する。
- [x] 対応済み：旧 `firmware/stackchan/main.ts` から renderer factory 経由の初期化を外し、`createAppControllerApplication` を直接呼ぶ構成へ移す。
- [x] 対応済み：`RobotUI`、`robot.ui`、`robot.drawer` を正規 API として導入する。
- [x] 対応済み：実装から `robot.renderer`、`useRenderer`、`addDecorator`、`removeDecorator` を削除する。
- [x] 対応済み：旧 Poco 系 renderer の tracked code を `firmware/stackchan/renderers` から削除する。
- [x] 対応済み：Piu UI 実装を旧 renderer 構造から `firmware/host/modules/ui` へ分離する。
- [x] 対応済み：分離済みの Piu UI 実装を `firmware/host/modules/ui` 配下へ移す。
- [x] 対応済み：Piu `Application` の生成と再利用を `firmware/host/modules/ui/application/app-controller.ts` に置く。
- [x] 対応済み：通常画面の実装を `firmware/host/modules/ui/views/main` に置く。
- [x] 対応済み：起動スプラッシュを `firmware/host/modules/ui/views/splash` に置く。
- [x] 対応済み：カメラプレビューを `firmware/host/modules/ui/views/camera-preview` に置く。
- [x] 対応済み：StatusBar を `firmware/host/modules/ui/components/status-bar` に置く。
- [x] 対応済み：Drawer を `firmware/host/modules/ui/components/drawer` に置く。
- [x] 対応済み：Effects を `firmware/host/modules/ui/components/effects` に置く。
- [x] 対応済み：SpeechBalloon と MultiRowBalloon を `firmware/host/modules/ui/components/bubble` に置く。
- [x] 対応済み：顔の部品、顔表示 Behavior、顔関連 skin を `firmware/host/modules/ui/components/face` に置く。
- [x] 対応済み：顔状態を `firmware/host/modules/ui/state` に置く。
- [x] 対応済み：UI 画像と UI フォントを `firmware/host/modules/ui/assets` に置く。
- [x] 対応済み：UI manifest と tsconfig から `renderer-*` alias を削除する。
- [x] 対応済み：`renderer` preference と config 名を `ui` へ置き換える。
- [x] 対応済み：default mod と sample mod の UI 呼び出しを `robot.ui.addEffect`、`robot.ui.removeEffect`、`robot.ui.setFace`、`robot.drawer` へ更新する。
- [x] 対応済み：`firmware/docs/api.md` と `firmware/docs/api_ja.md` の公開 API 説明を Renderer から RobotUI へ更新する。
- [x] 対応済み：設定画面の Piu 構築を app default behavior から `firmware/host/modules/ui/views/settings` へ移す。
- [x] 対応済み：`firmware/host/modules/ui/views/settings/settings-view.test.ts` を追加する。
- [x] 対応済み：`FaceContext` 名を view backed な `FaceState` へ置き換える。
- [x] 対応済み：顔状態を plain object ではなく Moddable の view 定義に寄せる。
- [x] 対応済み：`emotion` を文字列ではなく数値 enum として扱う。
- [x] 対応済み：theme 色の内部表現を `ColorRGB` 構造体に固定する。
- [x] 対応済み：Piu 境界でだけ `ColorRGB` を `0xRRGGBB` または `#rrggbb` へ変換する。
- [x] 対応済み：呼吸などの周期更新で `coordinates` を毎フレーム更新しない実装へ変える。
- [x] 対応済み：絵文字の描画更新を `Port`、`Texture`、必要最小の `invalidate` に寄せる。
- [x] 対応済み：標準顔の目は `Shape` と `Outline` で旧実装の表情形状を保ち、標準顔の口は固定領域の `Port` 描画に寄せる。
- [x] 対応済み：DogFace の眉、鼻、口は `Shape` と `Outline` で旧実装の曲線表現を保ち、量子化した path cache で更新する。
- [x] 対応済み：吹き出しの背景描画を `Texture`、`Skin` cache、`Port`、必要最小の `invalidate` に寄せる。
- [x] 対応済み：毎フレーム `new Skin()`、`new Style()`、`Label.string` 更新が発生しないことを確認する。
- [x] 対応済み：標準顔、DogFace、ImageFace の表情は Stack-chan の core 機能として扱い、描画最適化より visual parity を優先する受け入れ条件を追加する。
- [x] 対応済み：標準顔の目の既定色を旧実装と同じ白へ戻し、`FaceState.theme.primary` が実際の描画色へ反映される `Shape` と共有 `Skin` を使う。
- [x] 対応済み：lin で `Shape` の数値色 `Skin` が白ではなくシアンに見える退行を修正し、顔部品の `Skin` と sprite tint は `#rrggbb` 文字列で指定する。
- [x] 対応済み：標準顔のまぶたについて、旧 Shape 実装にあった `ANGRY`、`SAD`、`HAPPY`、`SLEEPY` の形状変化を復活させる。
- [x] 対応済み：DogFace の口を旧 `Outline.CanvasPath` の曲線表現へ戻す。
- [x] 対応済み：DogFace の眉、鼻、口について、旧 Shape 実装から失われた曲線、傾き、感情表現を復活させる。
- [x] 対応済み：呼吸、瞬き、サッケードを標準顔、DogFace、ImageFace に適用するデフォルトモーションへ戻す。
- [x] 対応済み：AppController 配下の実 Piu timer で `FaceBehavior` が動くことを `lin/m5stack` の Moddable test で検証する。
- [x] 対応済み：呼吸の移動量を整数ピクセルの目標 offset 差分にし、lin で小数 `moveBy` が丸め落とされても動きが消えないようにする。
- [x] 対応済み：呼吸、瞬き、サッケードのデフォルト有効範囲を手動確認結果から調整する。
- [x] 対応済み：UI performance の architecture check は `Shape` と `Outline` の一律禁止ではなく、hot path の allocation を抑える条件へ書き換える。
- [x] 対応済み：表情部品では `Shape` と `Outline` を許可し、禁止対象を `onTimeChanged` と高頻度 `onFaceState` 内の `new Outline.CanvasPath()`、`Outline.fill()`、`Outline.stroke()`、`new Skin()` に限定する。
- [x] 対応済み：連続値で変化する `open`、`eye.open`、感情表現は段階量子化し、量子化キーごとの path cache で再描画時の allocation を抑える。
- [x] 対応済み：色変更は palette と `Skin` cache の再利用で扱い、通常フレームでは `Skin` を作り直さない。
- [x] 対応済み：標準顔と DogFace は固定描画領域内の更新に寄せ、表情変化に伴う ui relocation を発生させない。
- [x] 対応済み：Bubble は texture atlas、`Skin` cache、`Port` 描画で置き換える。
- [x] 対応済み：Outline を使った Emoticon は sprite atlas と `Port` 描画へ置き換える。
- [x] 対応済み：Shape Mouth の再描画に伴う ui relocation は、標準顔の口を固定領域の `Port` 描画へ移して解消する。

### 2. アプリケーション層の分離

- [x] 対応済み：`firmware/host/app` を作成する。
- [x] 対応済み：トップレベルの実装ディレクトリを `firmware/stackchan` から `firmware/host` へ移す。
- [x] 対応済み：移行後の build、manifest、import から `firmware/stackchan` への参照を取り除く。
- [x] 対応済み：`firmware/stackchan/main.ts` を `firmware/host/app/main.ts` と `firmware/host/app/compose.ts` へ分ける。
- [x] 対応済み：`app/main.ts` は起動順序、manifest の選択、エラーハンドリングだけを持つ。
- [x] 対応済み：`app/compose.ts` は module の生成と依存注入だけを持つ。
- [x] 対応済み：ドライバ、TTS、UI、入力、センサ、LED、Wi-Fi、WASM、MOD の選択処理を root `main.ts` から移す。
- [x] 対応済み：`config.wasm` の runtime branch を app layer から取り除く。
- [x] 対応済み：WASM、lin、ESP32 の差分を platform manifest の include と modules で表す。
- [x] 対応済み：`firmware/stackchan/manifest*.json` を `firmware/host/app/manifest*.json` へ移す。
- [x] 対応済み：`firmware/package.json` の build、smoke、test script を新しい app manifest へ更新する。
- [x] 対応済み：製品既定動作を `firmware/host/app/default-behavior` に置く。
- [x] 対応済み：`firmware/stackchan/default-mods` を app default behavior へ移し、MOD ディレクトリを利用者向け拡張とサンプルに限定する。
- [x] 対応済み：installed MOD が存在する場合は product default behavior を実行せず、MOD だけを app behavior として起動する。

### 3. Robot Facade の分解

- [x] 対応済み：`firmware/host/app/runtime-context.ts` が driver、TTS、input、camera、LED、drawer、face、motion を直接抱える構造を解消する。
- [x] 対応済み：Face、Motion、Audio、Input、Lighting、Camera、Conversation、Connectivity の公開契約を個別に定義する。
- [x] 対応済み：`Robot` は互換 Facade として残さず、新しい app composition の戻り値または context 型へ置き換える。
- [x] 対応済み：MOD へ渡す API を `Robot` の肥大化ではなく、必要な capability を束ねた型として再定義する。
- [x] 対応済み：Drawer と Face は UI capability として公開し、motion や audio から直接参照しない。
- [x] 対応済み：product default behavior は `Robot` のメソッド追加ではなく、installed MOD が存在しない場合の app fallback behavior として登録する。

### 4. Modules 構造の作成

- [x] 対応済み：`firmware/host/modules/audio` を作成し、`manifest.json` と `manifest.test.json` を置く。
- [x] 対応済み：`firmware/host/modules/camera` を作成し、`manifest.json` と `manifest.test.json` を置く。
- [x] 対応済み：`firmware/host/modules/conversation` を作成し、`manifest.json` と `manifest.test.json` を置く。
- [x] 対応済み：`firmware/host/modules/connectivity` を作成し、`manifest.json` と `manifest.test.json` を置く。
- [x] 対応済み：`firmware/host/modules/input` を作成し、`manifest.json` と `manifest.test.json` を置く。
- [x] 対応済み：`firmware/host/modules/lighting` を作成し、`manifest.json` と `manifest.test.json` を置く。
- [x] 対応済み：`firmware/host/modules/motion` を作成し、`manifest.json` と `manifest.test.json` を置く。
- [x] 対応済み：`firmware/host/modules/preferences` を作成し、`manifest.json` と `manifest.test.json` を置く。
- [x] 対応済み：`firmware/host/modules/testing` を作成し、共有 fake と test helper を置く。
- [x] 対応済み：`firmware/host/modules/util` を作成し、`manifest.json` と `manifest.test.json` を置く。
- [x] 対応済み：module 群は `firmware/stackchan/components` ではなく `firmware/host/modules` に置く。
- [x] 対応済み：各 module は実装、manifest、test、test manifest、専用 fake を同じディレクトリに持つ。
- [x] 対応済み：二つ以上の module で使う fake timer、fake transport、fake provider、fake Piu event は `modules/testing` に置く。

### 5. Motion の移行

- [x] 対応済み：`firmware/stackchan/drivers` を `firmware/host/modules/motion` へ移す。
- [x] 対応済み：`scservo`、`rs30x`、`dynamixel` を `modules/motion/protocols` へ分ける。
- [x] 対応済み：首の pan、tilt、torque、追従制御を `modules/motion` の controller 層に置く。
- [x] 対応済み：`Rotation.fromVector3` と `MotionController` の pitch 計算を `sqrt(x^2 + y^2)` に揃え、x と y が異なるベクトルで検証する。
- [x] 対応済み：低レイヤの送受信待ちから `Promise` queue を取り除く。
- [x] 対応済み：低レイヤの送受信待ちは callback、待ち slot、timeout state で表す。
- [x] 対応済み：上位 API が待ち合わせを必要とする場合だけ、app 境界で callback を `Promise` に変換する。
- [x] 対応済み：fake motion driver と fake timer を追加し、Node test と lin build で motion controller の状態遷移を検証する。

### 6. Audio の移行

- [x] 対応済み：`firmware/stackchan/speeches` を `firmware/host/modules/audio` へ移す。
- [x] 対応済み：`firmware/stackchan/microphone.ts` を `firmware/host/modules/audio` へ移す。
- [x] 対応済み：`firmware/stackchan/tone.ts` を `firmware/host/modules/audio` へ移す。
- [x] 対応済み：`firmware/stackchan/transcriptions` を `firmware/host/modules/audio` へ移す。
- [x] 対応済み：`firmware/stackchan/assets/sounds` を `firmware/host/modules/audio/assets/sounds` へ移す。
- [x] 対応済み：`firmware/stackchan/wasm` の音声 stub を `firmware/host/modules/audio/wasm` へ移す。
- [x] 対応済み：TTS provider ごとの実装ファイルは維持し、audio module の manifest で選択する。
- [x] 対応済み：ストリーミング再生と再生完了通知を callback 契約へ統一する。
- [x] 対応済み：`onPlayed` と `onDone` の通知方向は維持し、`stream()` の戻り値へ完了制御を集めない。
- [x] 対応済み：録音 buffer と再生 buffer の所有者を型または契約で明示する。
- [x] 対応済み：大きい `ArrayBuffer` を多段でコピーしないことを audio test で確認する。
- [x] 対応済み：`m5stack_fire` では旧 `pins/audioin` と `embedded:io/audio/in` の native 名衝突を避けるため、manifest で `embedded:io/audio/in` を platform adapter に差し替える。

### 7. Conversation の移行

- [x] 対応済み：`firmware/stackchan/services/chat.ts` を `firmware/host/modules/conversation` へ移す。
- [x] 対応済み：`firmware/stackchan/dialogues` を `firmware/host/modules/conversation` へ整理する。
- [x] 対応済み：旧 provider demo は core から外し、会話デモとして残すものだけを `firmware/mods/examples` へ移す。
- [x] 対応済み：コアの会話実装は Moddable の `ChatAudioIO` を第一候補にする。
- [x] 対応済み：手製の会話 loop を新規に増やさない。
- [x] 対応済み：MCP tool 呼び出しは conversation から connectivity への明示依存として表す。
- [x] 対応済み：transcript と tool call の状態を conversation module の状態として扱う。

### 8. Connectivity の移行

- [x] 対応済み：`firmware/stackchan/services/http-server` を `firmware/host/modules/connectivity` へ移す。
- [x] 対応済み：`firmware/stackchan/services/mcp-client` と `firmware/stackchan/services/mcp-server` を `firmware/host/modules/connectivity` へ移す。
- [x] 対応済み：`firmware/stackchan/network-service.ts` を `firmware/host/modules/connectivity` へ移す。
- [x] 対応済み：`firmware/stackchan/services/preference-server.ts` を `firmware/host/modules/connectivity` へ移す。
- [x] 対応済み：`firmware/stackchan/services/wasm` の network/preference stub を `firmware/host/modules/connectivity/wasm` へ移す。
- [x] 対応済み：`firmware/stackchan/ble` を `firmware/host/modules/connectivity` へ移す。
- [x] 対応済み：ネットワーク接続とプロトコル処理を app 起動処理から外す。
- [x] 対応済み：接続状態は callback で通知する。
- [x] 対応済み：再接続と timeout は状態機械として実装する。
- [x] 対応済み：fetch を使う外部 API 境界では `Promise` を許容する。
- [x] 対応済み：内部イベント通知では `Promise` ではなく callback を使う。

### 9. Input、Lighting、Camera、Preferences、Util の移行

- [x] 対応済み：`firmware/stackchan/touch*` と `firmware/stackchan/imu*` を `firmware/host/modules/input` へ移す。
- [x] 対応済み：touch、touch panel、IMU の入力 callback を短い `InputEvent` へ正規化する。
- [x] 対応済み：`robot.button` の公開 API を `read()` 付き raw object ではなく `ButtonInputEvent` へ置き換える。
- [x] 対応済み：MOD 境界に公開される `robot.button.read()`、`touchPanel.sample()`、`imu.sample()` を event callback API へ置き換える。
- [x] 対応済み：`globalThis.button` を直接参照する起動時設定経路を設定 view の command へ置き換える。
- [x] 対応済み：入力の polling で `Timer.repeat(async () => ...)` を使わない。
- [x] 対応済み：`firmware/stackchan/led` を `firmware/host/modules/lighting` へ移す。
- [x] 対応済み：py32 差分を lighting module の platform manifest または module 内部差分として扱う。
- [x] 対応済み：`firmware/stackchan/camera.ts` を `firmware/host/modules/camera` へ移す。
- [x] 対応済み：camera の実機実装、WASM stub、lin stub を platform manifest で切り替える。
- [x] 対応済み：`firmware/stackchan/utilities` を `firmware/host/modules/util` と `firmware/host/modules/preferences` へ分ける。
- [x] 対応済み：数学系 helper は `modules/util` に置く。
- [x] 対応済み：`loadPreferences` と設定 schema は `modules/preferences` に置く。
- [x] 対応済み：`loadPreferences` を直接呼ぶ場所を app と preferences に限定する。
- [x] 対応済み：module 内で設定を読む必要がある場合は、app から注入された config を使う。
- [x] 対応済み：sample MOD が直接 preference を読む境界を許可するか、注入 config に寄せるかを決める。

### 10. Platform 層の分離

- [x] 対応済み：`firmware/host/platforms/wasm` を作成する。
- [x] 対応済み：`firmware/host/platforms/lin` を作成する。
- [x] 対応済み：`firmware/host/platforms/esp32` を作成する。
- [x] 対応済み：`firmware/host/platforms/m5stackchan_cores3` を作成する。
- [x] 対応済み：module 固有ではない WASM platform 差分を `firmware/host/platforms/wasm` へ移す。
- [x] 対応済み：通常コードから WASM 専用 import を取り除く。
- [x] 対応済み：platform 差分を TypeScript の runtime branch ではなく manifest の include、modules、platforms で表す。
- [x] 対応済み：ESP32 target ごとの差分を platform manifest で表し、app composition に混ぜない。
- [x] 対応済み：`m5stack_fire` の audio input 差分を app composition ではなく audio module の platform manifest で表す。

### 11. MOD と sample の整理

- [x] 対応済み：変更対象になった default mod と sample mod の Renderer API 呼び出しを RobotUI API へ更新する。
- [x] 対応済み：`firmware/mods` を利用者向け MOD と sample だけを置く場所にする。
- [x] 対応済み：sample MOD を `firmware/mods/examples` へ移す。
- [x] 対応済み：product default behavior を `firmware/mods` から `firmware/host/app/default-behavior` へ移す。
- [x] 対応済み：古い provider demo を core 依存から切り離す。
- [x] 対応済み：MOD API の公開面を capability 単位で再定義し、旧 `Robot` 互換 API を残さない。
- [ ] 未対応：sample MOD を TypeScript source として型検査できる構成へ移す。
      `mcrun -p lin` など TypeScript module 対応済み target で build し、stack-chan 側に独自の generated JavaScript prebuild を持たない。
      WASM host 用の MOD も、この build で生成した `.xsb` またはそれを含む archive を読み込ませる。
- [ ] 未対応：sample MOD を `StackchanContext` の公開 capability 型に合わせて書き直す。
      `driver`、`useTTS`、streaming microphone など、現行の公開 API に存在しない呼び出しは、公開 capability を追加するか sample 側から外す。
- [ ] 未対応：MOD から `StackchanContext` などの公開型を `import type` できる module specifier を用意する。
      実行時 module を増やさず、型配布だけを目的にする。

### 12. テスト配置と実行方法の移行

この節では、テストを移動して実行できる状態と、振る舞いを保証する状態を分けて扱う。

ソースコード文字列の正規表現検査は、移行漏れ検出または構成検査であり、振る舞いテストとして数えない。

- [x] 対応済み：`firmware/tests` の内容を対象 module または UI ディレクトリへ移す。
- [x] 対応済み：`firmware/tests/unit` の内容を対象 module または UI ディレクトリへ移す。
- [x] 対応済み：集約テストディレクトリとしての `firmware/tests` を削除する。
- [x] 対応済み：各 module と UI view に `manifest.test.json` を置く。
- [x] 対応済み：各 `manifest.test.json` は本体の `manifest.json` と `modules/testing/manifest.json` を include する。
- [x] 対応済み：テスト用 `modules.main` は同じディレクトリの `*.test.ts` または `*.test.js` を読む。
- [x] 対応済み：成功時は `ok` を trace し、失敗時は例外を throw する。
- [x] 対応済み：合否判定は `mcconfig -m -d -p <platform> -t build` で生成した `mcsim` を xsbug ログ監視で実行し、`ok` trace と例外 marker で行う。
- [x] 対応済み：`trace("not ok ...")` を合否判定に使わない。
- [x] 対応済み：Node.js の `node:test` は移行補助と pure helper の検証に限定する。
- [x] 対応済み：`mcconfig -m -d -p lin/m5stack -t run` は現在の lin/m5stack makefile に存在しないため、正規手順から外す。
- [x] 対応済み：移行後の正規テスト判定は `npm run test:moddable` に寄せる。
- [x] 対応済み：CI は `firmware/host/app/**/manifest.test.json`、`firmware/host/modules/**/manifest.test.json`、`firmware/mods/examples/**/manifest.test.json` を列挙して実行する。
- [x] 対応済み：CI は Piu を使う `host/app`、`host/modules/ui`、sample MOD の test manifest を `lin/m5stack` で実行できる。
- [x] 対応済み：Piu の Application や描画イベントを使うテストは `lin/m5stack` を既定にする。
- [x] 対応済み：画面を使わない純粋ロジックは `lin` で実行できるようにする。
- [x] 対応済み：実機依存の確認は unit test ではなく smoke として分ける。
- [x] 対応済み：`firmware/host/modules/ui/views/splash/splash-view.test.ts` のソース文字列 assert を棚卸しし、振る舞いテスト、manifest 構造検査、移行漏れ検査へ分類し直す。
- [x] 対応済み：起動スプラッシュと起動時選択について、`assert.match(source, ...)` と `assert.doesNotMatch(source, ...)` で実装行を追認しているテストを、振る舞いテストの達成条件から外す。
- [x] 対応済み：`$MODDABLE/documentation/xs/xst.md`、`$MODDABLE/xs/tools/xst.c`、`$MODDABLE/tests` 配下の既存テストを読み、`$DONE`、`$DO`、`$TESTMC.timeout`、async module の扱いを確認したうえで、今回の対象は Node.js の pure helper test と `mcconfig` 生成 `mcsim` の Piu test へ分類する。
- [x] 対応済み：Moddable API に依存するテストは、`xst` で足りるもの、`mcconfig` で生成した `mcsim` が必要なもの、実機 smoke に回すものへ分ける。
- [x] 対応済み：起動時選択の待ち合わせを `app-default-behavior/startup-choice` のような明示的な module 識別子で import できる単位へ切り出す。
- [x] 対応済み：起動時選択テストでは fake timer、fake Application、fake splash hook を注入し、3秒後の自動 boot、タッチ時の settings 遷移、二重 resolve の抑止、選択後の後始末を検証する。
- [x] 対応済み：起動スプラッシュのテストでは `showStartupSplash` の戻り値、Piu tree、Label 表示、touch callback を `lin/m5stack` の test manifest 上で検証し、`new Application` や `new Label` の文字列検査に依存しない。
- [x] 対応済み：WASM default behavior のテストでは、manifest が解決する module 識別子と起動 hook の呼び出し結果を検証し、`app-default-behavior/wasm/on-launch` という文字列の有無だけを合否にしない。
- [x] 対応済み：Moddable に依存しない pure helper は Node.js でテストしてよいが、相対パス import ではなく manifest と同じ module 識別子を解決する loader または alias 設定を用意する。
- [x] 対応済み：Node.js テストで Moddable global、Timer、Piu、Modules、Preference を扱う場合は、明示的な mock を注入し、実装ファイルの文字列走査で代用しない。
- [x] 対応済み：構成検査として残すソース文字列検査は `check:legacy-names` または architecture lint に寄せ、振る舞いテストと別の名前で CI に表示する。
- [x] 対応済み：書き換え後のテストを `npm run test:unit`、`npm run test:moddable`、必要に応じて `xst` 直接実行で検証し、PR の Validation に分けて記録する。
- [x] 対応済み：`npm run test:moddable` の既定列挙対象に `host/app` の runnable `manifest.test.json` を含める。
- [x] 対応済み：sample MOD の `manifest.test.json` は CI 対象として扱い、`npm run test:moddable` と文書の説明を一致させる。
- [x] 対応済み：Piu を使う `host/app` と sample MOD の Moddable test は、`lin` ではなく `lin/m5stack` で実行する条件を `run-module-tests.js` に入れる。
- [x] 対応済み：production manifest の `app-default-behavior/*` を明示的な module specifier の列挙へ置き換える。
- [x] 対応済み：production manifest が `*.test.ts`、`*.architecture.ts`、`__tests__` を解決対象に含む場合に失敗する architecture check を追加する。
- [x] 対応済み：`*.test.ts` に残っている manifest 固定テストを `*.architecture.ts` または manifest preflight へ移す。
- [x] 対応済み：installed MOD が product default behavior を置き換える構成を architecture check で検査する。
- [x] 対応済み：installed MOD が存在する場合に product default behavior を app behavior 配列へ含めないことを Node.js の挙動テストで検証する。

### 13. 非同期境界の移行

- [x] 対応済み：Timer、Piu Behavior、driver、input handler の中で新規 `async` 関数を使わない。
- [x] 対応済み：低レイヤの待ち合わせは callback と状態 enum で進める。
- [x] 対応済み：戻り値に `Promise` を返す関数は network fetch、外部 API、app 境界、test helper に限定する。
- [x] 対応済み：周期更新する状態は固定構造を再利用する。
- [x] 対応済み：毎フレーム動く処理で object を生成しない。
- [x] 対応済み：色、感情、状態は内部で数値として扱う。
- [x] 対応済み：ログ、設定ファイル、Piu 描画、表示文字列へ出す境界でだけ文字列へ変換する。
- [x] 対応済み：継続可能な状態変化（servo command busy、wait slot 重複、任意ハードウェア初期化失敗）は例外ではなく戻り値または callback で通知する。
- [x] 対応済み：module 境界の同期エラーは motion protocol の `onError` や PY32 の `tryGet...` callback で通知し、設定不備や構築 invariant の例外だけを残す。

### 14. 旧文書と参照の整理

- [x] 対応済み：`firmware/docs/api.md` と `firmware/docs/api_ja.md` の Renderer API 記載を RobotUI API へ更新する。
- [x] 対応済み：`docs/piu-renderer.md` を削除または新 UI 設計文書へ置き換える。
- [x] 対応済み：`docs/piu-renderer_ja.md` を削除または新 UI 設計文書へ置き換える。
- [x] 対応済み：`firmware/docs/0002-image-face.md` の旧 renderer 前提を削除または更新する。
- [x] 対応済み：`firmware/face-context-as-views.md` を `FaceState` 方針に合わせて削除または更新する。
- [x] 対応済み：`firmware/piu-faster.md`（現 `firmware/docs/piu-performance-policy.md`）を UI performance 方針として統合する。
- [x] 対応済み：`AGENTS.md` の旧構成参照を削除または更新する。
- [x] 対応済み：`renderer.type`、`renderers-piu`、旧 renderer API を説明する残存文書を削除または更新する。
- [x] 対応済み：tracked tree に旧 `firmware/stackchan/renderers` と旧 `firmware/stackchan/renderers-piu` が残っていないことを確認する。
- [x] 対応済み：ローカルに空ディレクトリが残る場合でも、manifest、import、document から参照しない。
- [x] 対応済み：`firmware/chat.md`（現 `firmware/docs/chat-audioio-integration.md`）の `Robot/Mod`、`FaceContext`、旧 `tests/chats/` 前提を `StackchanContext`、capability API、移行後の test 配置へ更新する。

### 15. 検証

- [x] 対応済み：UI 互換層削除後に `npm run format` を実行する。
- [x] 対応済み：UI 互換層削除後に `npm run lint` を実行する。
- [x] 対応済み：UI 互換層削除後に `npm run test:unit` を実行する。
- [x] 対応済み：UI 互換層削除後に `npm run build:wasm` を実行する。
- [x] 対応済み：UI 互換層削除後に `npm run smoke:lin` を実行する。
- [x] 対応済み：UI 互換層削除後に web 側の `npm test` を実行する。
- [x] 対応済み：UI 互換層削除後に変更対象 MOD の mcrun を実行する。
- [x] 対応済み：UI 互換層削除後に lin 向け manifest 群の build を確認する。
- [x] 対応済み：module 移行後に `npm run format` を再実行する。
- [x] 対応済み：module 移行後に `npm run lint` を再実行する。
- [x] 対応済み：module 移行後に `npm run test:unit` を再実行する。
- [x] 対応済み：module 移行後に `npm run build:wasm` を再実行する。
- [x] 対応済み：module 移行後に `npm run smoke:lin` を再実行する。
- [x] 対応済み：module 移行後に web 側の `npm test` を再実行する。
- [x] 対応済み：module 移行後に `firmware/host/modules/**/manifest.test.json` をすべて実行する。
- [x] 対応済み：module 移行後に `firmware/host/modules/ui/**/manifest.test.json` をすべて実行する。
- [x] 対応済み：module 移行後に対象 ESP32 board の build を実行する。
- [x] 対応済み：module 移行後に changed MOD と sample MOD の `mcrun -t build` を実行する。
- [x] 対応済み：module 移行後に旧 API 検索を実行し、許可した移行計画文書と検査テスト以外に旧名が残らないことを確認する。
- [x] 対応済み：`npm run check:legacy-names` で検出される旧 renderer 文書と generated API docs を削除または更新する。
- [x] 対応済み：ソースコード文字列の追認に依存している UI 起動テストを振る舞いテストへ置き換えた後で、`npm run test:unit`、`npm run test:moddable`、必要な `xst` 検証を再実行する。
- [x] 対応済み：描画復元後に対象ファイルの `npx biome lint` を実行する。
- [x] 対応済み：描画復元後に `npm run check:architecture` を実行する。
- [x] 対応済み：描画復元後に `npm run test:unit` を実行する。
- [x] 対応済み：描画復元後に `host/modules/ui/components/face/__tests__/face-rendering/manifest.test.json` を `lin/m5stack` で実行し、標準顔、DogFace、ImageFace の描画状態と実 Piu timer による呼吸、瞬きを検証する。
- [x] 対応済み：描画復元後に `npm run test:moddable -- host/modules/ui` を実行し、UI 配下の Moddable test manifest を `lin/m5stack` で検証する。
- [x] 対応済み：描画復元後に `npm run smoke:lin` を実行する。
- [x] 対応済み：描画復元後に `npm run build:wasm` を実行する。
- [x] 対応済み：ユーザーの手元の `lin/m5stack` で標準顔、DogFace、ImageFace を表示し、既定色、口形状、呼吸、瞬き、サッケードを目視で確認する。
- [x] 対応済み：表示退行を検出するため、`lin/m5stack` の描画状態を使った visual smoke を追加する。

### 16. Merge 条件

注：移行計画の完遂後も、`develop` へのマージは行わず、PR の作成までを作業範囲とする。

- [x] 対応済み：app layer が module の生成と接続だけを行っている。
- [x] 対応済み：`Robot` が全機能を抱える Facade ではなくなっている。
- [x] 対応済み：Piu が `Renderer` 互換層を経由していない。
- [x] 対応済み：Piu Application、View、Drawer、StatusBar、Bubble、Effects、Face が `firmware/host/modules/ui` 配下にある。
- [x] 対応済み：各機能の本体、単体テスト、test manifest が同じ module または UI ディレクトリにある。
- [x] 対応済み：`firmware/tests` が存在しない。
- [x] 対応済み：低レイヤの Timer、描画、入力、driver 処理に新規 `async` と `Promise` が入っていない。
- [x] 対応済み：platform 差分が manifest で切り替わる。
- [x] 対応済み：通常コードに WASM 専用 import が混ざっていない。
- [x] 対応済み：後方互換用の import alias、deprecated API、移行 adapter が残っていない。
- [x] 対応済み：lin unit、lin smoke、web test、WASM build、対象 ESP32 build が通っている。
- [x] 対応済み：起動スプラッシュと起動時選択のテストが、ソースコード文字列の追認ではなく実行時の振る舞いを検証している。

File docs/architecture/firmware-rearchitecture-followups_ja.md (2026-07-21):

# ファームウェア再設計の振り返りと改善課題

作成日：2026-06-30

対象：`firmware/host`、`firmware/mods`、Moddable manifest、CI。

この文書は、ファームウェア再設計移行作業で時間がかかった箇所を、今後の設計改善課題として整理する。

移行計画そのものは [firmware-rearchitecture_ja.md](./firmware-rearchitecture_ja.md) で管理する。

## 1. Moddable manifest の glob と Node.js テスト配置

### 起きた問題

`host/app/default-behavior/startup-choice.test.ts` を実装ファイルの近くに置いたところ、app manifest の `app-default-behavior/*` がそのテストファイルを拾った。

その結果、ESP32 build が Node.js 専用の `node:assert/strict`、`node:test`、`node:path`、`node:url` を解決しようとして失敗した。

これは個別の配置ミスではなく、production manifest の解決範囲と Node.js 専用ファイルの所属が機械的に分離されていないことを示している。

### 解決策

production manifest では、公開したい module surface をできるだけ明示列挙する。

`app-default-behavior/*` のような広い glob は、実装の近くに置いた検査用ファイルまで公開面へ混入させる。

`default-behavior` の公開面は小さいため、次のような明示指定に寄せられる。

```json
{
  "modules": {
    "app-default-behavior": "./default-behavior/behavior",
    "app-default-behavior/on-launch": "./default-behavior/on-launch",
    "app-default-behavior/on-context-created": "./default-behavior/on-context-created",
    "app-default-behavior/startup-choice": "./default-behavior/startup-choice"
  }
}
```

Node.js 専用テストは、production manifest の glob 範囲外に置く。

そのうえで、production manifest が `*.test.ts`、`*.architecture.ts`、`__tests__` を解決対象に含んだら失敗する architecture check を追加する。

## 2. テストと構成検査の境界

### 起きた問題

`assert.match(source, ...)` のような検査が unit test に混ざっていた。

この検査は移行漏れや構成制約の確認としては有効だが、振る舞いを検証していない。

unit test に混ざると、実装行の追認を振る舞いテストと誤認しやすい。

### 解決策

`*.test.ts` は、振る舞い、データ構造、公開 API の検証に限定する。

`*.architecture.ts` は、module 配置、import 禁止、manifest 構造、legacy 名禁止、hot path 制約の検査を担当する。

CI では `npm run test:unit` と `npm run check:architecture` を別ステップとして表示する。

この分離により、失敗したときに「振る舞いが壊れた」のか「構成制約に反した」のかを切り分けられる。

## 3. Node.js で Moddable の module 識別子を扱う方法

### 起きた問題

Moddable では manifest の `modules` によって `app-default-behavior/startup-choice` のような module 識別子を解決する。

Node.js の `node:test` で同じ module 識別子を使うには、alias package を手作業で作る必要があった。

相対 path import に逃げると、Moddable manifest と異なる経路でテストすることになる。

### `mcpack` との関係

`mcpack` は package entry から import graph を読み、package の manifest や相対 source をもとに一時 manifest を生成する。

そのため、「人間が Moddable の module map を手で再現する」問題を減らす方向には近い。

ただし、今回必要だったのは Node.js test runner で Moddable manifest の module 識別子を解決する仕組みである。

`mcpack` は Moddable build 用の manifest 生成には向くが、Node.js 用 loader としてそのまま使うものではない。

### 解決策

短期的には、相対 import の使い方を lint で制限する。

同一 component 内の `./types` のような import は許可し、`../..` で別 module へ抜ける import を禁止する。

`mods` ではより厳しく、host 公開 API は manifest module specifier だけを使う。

中期的には、manifest の `modules` 解決を Node.js テスト用 alias に変換する共通ハーネスを作る。

このハーネスは fake `timer`、fake Piu、fake `Modules`、fake `Preference` の注入も標準化する。

## 4. resource と font の整合性検査

### 起きた問題

resource や font は、単純なファイル存在確認だけでは不十分である。

Moddable manifest は include、platform 条件、resources の pseudo target、font の `characterFiles` などを統合して解決する。

自前の JSON 走査だけでは、Moddable が実際に見る結果とずれる可能性がある。

### 解決策

最初の段階では、自前 manifest の `modules`、`resources`、`data` の source 存在確認を行う。

次の段階で、include と platform 条件を統合した manifest に対して検査する。

最終的には、`mcconfig` が生成する `manifest_flat.json` または Moddable の manifest resolver に寄せて検査する。

検査項目は次を想定する。

- module source が存在する。
- resource source が存在する。
- font source が存在する。
- font の `characterFiles` が存在する。
- production manifest に test 用ファイルが混入していない。
- sample MOD が host 公開 module specifier だけを参照している。

## 5. `default-behavior` と MOD の置換規則

### 起きた問題

旧 `default-mods` は名前に `mods` を含むが、実際には利用者が導入する MOD ではなく、製品組み込みの default behavior だった。

この名前と実態のずれが、host と mods の境界を読み取りづらくしていた。

また、default behavior を app behavior として常時追加すると、installed MOD と同時に実行される。

これは従来挙動と異なる。

従来は、MOD が存在する場合は MOD を優先し、製品既定動作は実行しなかった。

### 解決策

`default-behavior` は `firmware/host/app/default-behavior` に置く。

ただし、実行規則は installed MOD の fallback に限定する。

`Modules.has("mod")` が true の場合、host は `mod` だけを import して実行する。

この場合、product default behavior は `onLaunch` も `onContextCreated` も実行しない。

`Modules.has("mod")` が false の場合だけ、host に同梱した product default behavior を実行する。

この規則により、利用者 MOD のボタン割り当てや画面操作を default behavior が上書きしない。

また、`firmware/mods` は利用者向け MOD と sample MOD だけを置く場所として維持できる。

## 6. sample MOD の TypeScript 化

### 起きた問題

sample MOD の API 齟齬は、MOD が JavaScript で書かれており、`StackchanContext` 型で検査されていなかったことが根本原因の一つである。

TypeScript で書けば、存在しない `driver`、`useTTS`、streaming microphone などの呼び出しを早く検出できる。

標準の `npm run mod` は `mcrun` へ MOD manifest を渡す経路である。

Moddable の `mcconfig`、`mcpack`、および ESP32、lin などの make fragment を持つ `mcrun` 経路は TypeScript source を扱える。

WASM host は、lin や esp32 向けに build した MOD の `.xsb` を読み込める。

そのため、WASM host で実行する MOD であっても、MOD 自体の build target を `wasm` にする必要はない。

WASM `mcrun` の `make.json` 経路に TypeScript support を追加することは、この移行の前提にしない。

### 解決策

sample MOD は TypeScript source で書く。

MOD の build は、Moddable の `mcrun` が持つ TypeScript module 経路をそのまま使う。

ローカル確認と CI では、デバイスなしで実行しやすい `lin` target を標準にする。

ESP32 実機へ install する場合は、従来どおり対象 device target を指定する。

stack-chan 側には、TypeScript を generated JavaScript へ事前変換する独自 workflow を持たない。

WASM host での確認では、`lin` などで build した `.xsb` またはそれを含む archive を読み込ませる。

TypeScript 化では、単に拡張子を変えるだけでは不十分である。

sample MOD は `StackchanContext` の公開 capability だけを import し、host 内部 module へ相対 path で依存しないようにする。

不足している機能がある場合は、sample 側の呼び出しを削るか、host の公開 capability として設計してから追加する。

### 確認すべき点

- `lin` target で build した TypeScript MOD の `.xsb` または archive を WASM host が継続して読み込めるか。
- WASM host 用に配布する MOD で、platform 固有の native code や resource 前提が混入していないか。
- source map や xsbug 上の行番号をどう扱うか。
- sample MOD の型チェックを CI の軽量 preflight に含められるか。
- `StackchanContext` 型を利用者 MOD から import できる公開 module specifier にできるか。
- TypeScript source の相対 import が host 内部境界を越えていないことを lint で保証できるか。

## 7. CI と preflight

### 起きた問題

ESP32 build、CoreS3 build、Moddable manifest test、WASM bundle は重い。

失敗が push 後や重い build の後半で見つかると、修正の往復が大きくなる。

実際に、Node.js 専用テストが production manifest に混入した問題は、ESP32 build で初めて見つかった。

### pre-commit

pre-commit では、`biome check --staged --error-on-warnings` を通す。

この検査は format、lint、import 整理、Biome warning の検出に向く。

一方で、TypeScript 型チェック、manifest 解決、resource 解決、ESP32 固有 build 失敗は検出できない。

### `mcconfig` の生成だけを使う preflight

`mcconfig` は `-m` を付けない場合、make を実行しない。

たとえば次のコマンドは、manifest 解決と生成物作成で止まる。

```sh
mcconfig -d -p esp32/m5stack -t build "$PWD/host/app/manifest_local.json"
```

この段階で確認できるものは、manifest parse、include 解決、platform 条件の merge、`modules`、`resources`、`data` の glob 展開、Moddable 用 tsconfig 生成である。

`-m` なしでは `tsc` は実行されない。

Moddable の実装では、`-m` が指定されたときだけ `this.make = true` になり、`make` または `nmake` が実行される。

`tsc -p ...` は生成された makefile の rule として書かれるため、make が走るまで実行されない。

### preflight の候補

CI の build 前に、軽量な manifest preflight を置く。

```sh
mcconfig -d -p esp32/m5stack -t build "$PWD/host/app/manifest_local.json"
mcconfig -d -p esp32/m5stack_cores3 -t build "$PWD/host/app/manifest_local.json"
mcconfig -d -p wasm -t build "$PWD/host/app/manifest_wasm.json"
```

このpreflightでは、Moddable が出す `no modules match` や `no resources match` の warning を分類する。

既知の warning は許可し、許可リスト外の missing module や missing resource は失敗にする。

### 型チェックだけの候補

公式オプションだけでは、manifest 解決後の TypeScript 型チェックだけを実行する方法は見当たらない。

実現するなら、次の手順を独自スクリプトにする。

1. `mcconfig` を `-m` なしで実行する。
2. 生成された `$MODDABLE/build/tmp/.../modules/*-tsconfig.json` を読む。
3. 対象 module の `tsc -p` を実行する。

この方法なら、Moddable が生成した module specifier 解決を使いながら、native build より前に TypeScript error を検出できる。

## 8. bundle workflow

### 起きた問題

bundle は時間がかかる。

PR ごとに実行すると、フィードバックが遅くなる。

### 解決策

本物の bundle は `develop` への merge 後に実行する。

PR では、bundle できる可能性を軽量に保証する preflight を実行する。

軽量 preflight では、bundle manifest の存在、bundle metadata、対象 manifest の解決、resource path の存在、WASM manifest の解決を確認する。

必要であれば、`mcbundle` を `-m` なしで実行し、shell script 生成までを確認する。

`mcbundle` も `-m` を付けた場合に実ビルドへ進むため、PR では生成のみ、merge 後に実ビルドという分担にできる。

## 9. 今後の優先順位

短期の改善は次の順で進める。

1. production manifest の広い glob を明示列挙へ寄せる。(実装済み)
2. production manifest に test 用ファイルが混入しない architecture check を追加する。(実装済み)
3. `mcconfig` 生成だけの `check:manifest` を追加する。(実装済み: `npm run check:manifest`)
4. `check:manifest` で Moddable warning を分類し、未知の missing module と missing resource を失敗扱いにする。(実装済み: `scripts/check-manifest.js` の allowlist)
5. 相対 import の lint を追加し、module 境界を越える相対 import を禁止する。
6. sample MOD の TypeScript 化と公開型 specifier を追加する。
7. 生成済み Moddable tsconfig を使った TypeScript preflight を検討する。

この順序なら、重い build を減らす前に、build でしか見つからなかった問題を軽量検査へ移せる。

## 10. 設計上の結論

今回の作業で見えた課題は、`host` と `mods` の境界だけではない。

各 source file がどの build world に属するかを、manifest と lint で宣言的に保証する必要がある。

具体的には、production firmware、Node.js unit test、architecture check、Moddable manifest test、利用者 MOD、sample MOD を、配置と検査で区別する。

この区別が曖昧なままだと、機能追加時に build 対象の混入、相対 import の漏れ、resource path の不整合が再発する。

再設計後の次の課題は、module の所有権だけでなく、検査対象と build world の所有権も明文化することである。

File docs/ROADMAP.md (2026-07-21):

# Stack-chan Development Roadmap

Last updated: 2026-03-27

## Purpose

This document defines an execution-oriented roadmap for Stack-chan.

The core goal is to reduce setup and development overhead without losing the qualities that make Stack-chan valuable today:

- Fast to iterate
- Hackable by default
- Extensible across firmware, mods, AI, and tooling

## Planning Principles

- Browser-first, not browser-only. Advanced local development remains available, but common workflows should not require Moddable or ESP-IDF setup.
- Standardize interfaces before expanding features. Mod format, AI pipeline, logs, and event contracts should be stabilized before multi-vendor or multi-agent expansion.
- Preserve the host/MOD architecture. The existing fast MOD iteration loop is a strategic advantage and should remain central.
- Stabilize AI behavior before adding advanced AI capabilities. Choppy TTS and opaque runtime behavior should be solved before vision, wake word, or swarming.
- Keep beginner and expert workflows aligned. Visual tools and educational flows should converge on the same runtime and packaging model used by advanced mod development.

## Current Baseline

As of 2026-03-27, the repository already provides several strong building blocks:

- Host and MOD are separated, enabling fast MOD-only deployment.
- Browser-based firmware flashing already exists.
- Browser-based preference editing over BLE already exists.
- TTS support and AI-related demos exist, but setup still depends on external services and manual configuration.
- Local development setup is still heavy for many users, especially outside an established Moddable environment.

This means the roadmap should focus on turning existing pieces into a coherent platform, not replacing them.

## Strategic Priorities

1. Define the minimum 2026 architectural refactor needed to support the next 5 years.
2. Make the standard development loop work from the browser for the majority of users.
3. Stabilize AI Stack-chan by making the audio pipeline observable and debuggable.
4. Introduce a pluggable AI pipeline so STT, LLM, and TTS vendors can be swapped without rewriting applications.
5. Expand the ecosystem with asset tooling and educational entry points.
6. Pursue advanced capabilities such as vision, wake word, and swarming only after the core platform is stable.

## Roadmap

| Phase | Target period | Goal | Main deliverables | Exit criteria |
| --- | --- | --- | --- | --- |
| Phase 0 | April 2026 to May 2026 | Align architecture and measure the current system | Platform position paper, mod packaging decision, AI pipeline contract draft, structured log schema, build pipeline foundation, release flow definition, AI-driven development conventions | Team agrees on platform boundaries, core artifacts can be built and released through an agreed flow, AI agents operate within defined instructions and validation gates, and baseline measurements for setup effort and TTS quality are captured |
| Phase 1 | June 2026 to August 2026 | Ship a browser-first development MVP | Improved web flashing flow, browser-based mod editing/upload path, security and sandbox policy, machine-readable test/log output, browser simulator feasibility prototype | A supported user can flash firmware and iterate on a sample mod without local SDK installation |
| Phase 2 | August 2026 to October 2026 | Stabilize AI Stack-chan in production-like conditions | Runtime instrumentation for audio, root-cause analysis of choppy TTS, buffer and scheduler fixes, developer-friendly API key setup flow | TTS issues can be reproduced, measured, and improved with clear diagnostics and agreed thresholds |
| Phase 3 | October 2026 to December 2026 | Standardize the pluggable AI runtime | ChatAudioIO-compatible interface, STT/LLM/TTS adapter layer, latency budget per stage, local-vs-cloud reference architecture, compatibility docs | Applications can switch supported AI providers mostly by configuration rather than application rewrites |
| Phase 4 | January 2027 to March 2027 | Expand creation tools for broader adoption | Web face editor beta, asset format standardization, runtime vs build-time asset loading guidance, visual programming prototype | A beginner can create a face or simple behavior and deploy it through the same platform model used by advanced users |
| Phase 5 | April 2027 and beyond | Explore advanced AI and multi-device experiences | Vision trigger experiments, wake word architecture decision, swarming/event sync prototypes, enterprise-ready scenario explorations | Advanced features are evaluated on top of stable contracts instead of one-off implementations |

## Phase Details

### Phase 0: Architecture and Baselines

This phase turns the remaining architectural and platform questions into explicit decisions.

Scope:

- Define how Stack-chan should be positioned in 2026:
  - hardware kit
  - firmware platform
  - conversational robot OS
  - foundation for a distributed AI agent ecosystem
- Decide what must be standardized first:
  - mod format
  - AI pipeline contract
  - structured log format
  - event bus boundary
- Establish the build pipeline and release flow needed for core artifacts:
  - define what gets built and validated on each change
  - define release boundaries between firmware, mods, and web tooling
  - make releases reproducible and reviewable
- Define the foundation for AI-driven development:
  - define repository-level conventions for `Skills` and `AGENTS.md`
  - define which tasks AI agents may execute autonomously and where human review is required
  - make `xst` and TypeScript checks part of the minimum validation gate for autonomous changes
- Capture baseline metrics:
  - time to first flash
  - time to first MOD iteration
  - failure points in environment setup
  - TTS glitch frequency under reference conditions

Recommended outputs:

- `docs/architecture/2026-platform-direction.md`
- `docs/specs/mod-format.md`
- `docs/specs/ai-pipeline.md`
- `docs/specs/log-schema.md`
- `docs/operations/build-pipeline.md`
- `docs/operations/release-flow.md`
- `docs/operations/ai-driven-development.md`
- `AGENTS.md`

### Phase 1: Browser-First Developer Experience

This phase addresses one of the biggest sources of developer overhead today: setup complexity.

Scope:

- Make firmware flashing, settings, and mod development feel like one connected browser workflow.
- Define whether mods stay source-based, become packaged bundles, or support both with a canonical transport format.
- Design the sandbox and permission model for browser-driven and LLM-generated mods.
- Establish a scenario/test format so browser execution results are reusable by humans, CI, and LLM tooling.
- Build a realistic simulator spike to determine how much of the current runtime can move to WebAssembly.

Priority outcomes:

- Zero-install or minimal-install flow for common tasks
- One-click write to device after validation
- Logs with `error_code`, trace, timing, and memory fields
- A clear policy for auto-fix loop stop conditions and human approval before flashing

### Phase 2: AI Stabilization

This phase turns AI Stack-chan from a promising demo path into a diagnosable system.

Scope:

- Instrument the audio path end to end.
- Isolate the dominant causes of choppy TTS:
  - network latency
  - buffer underflow
  - task scheduling contention
  - GC pauses
- Redesign buffer management if required.
- Improve key and secret provisioning so AI setup becomes secure but not hostile to developers.

Priority outcomes:

- Reproducible diagnostic scenarios
- Shared telemetry vocabulary for AI failures
- Documented performance envelope for supported reference devices

### Phase 3: Pluggable AI Pipeline

This phase reduces cost lock-in and enables experimentation.

Scope:

- Normalize the interface between STT, LLM, and TTS stages.
- Provide adapter implementations for the most important providers and reference local/cloud hybrids.
- Define latency budgets and fallback behavior per stage.
- Ensure application logic can stay provider-agnostic where practical.

Priority outcomes:

- A reference pipeline that supports vendor replacement
- Documentation for adapter contracts and expected capabilities
- A baseline for future embedded conversational robot integrations

### Phase 4: Ecosystem Tooling

This phase grows the creator ecosystem once the platform contracts are stable.

Scope:

- Ship a web-based face asset workflow.
- Standardize asset packaging and transfer.
- Decide when runtime asset loading is appropriate versus build-time embedding.
- Prototype a visual programming layer for children and first-time developers.
- Validate coexistence with advanced mod development rather than creating a separate ecosystem.

Priority outcomes:

- Asset tools that produce first-class platform artifacts
- An educational profile that lowers barriers without hiding the underlying model too much

### Phase 5: Advanced Capabilities

These items remain important, but they should not lead the roadmap until the platform core is in place.

Scope:

- Vision-based triggers and recognition
- Wake word detection
- Multi-device conversation and synchronized behavior
- Enterprise-ready and multilingual scenario validation

Required prerequisites:

- Stable AI pipeline contracts
- Defined event bus and synchronization model
- Reliable coexistence strategy for BLE and Wi-Fi
- Measured CPU, memory, and latency headroom on target hardware

## Dependency Rules

The roadmap intentionally enforces the following order:

- Browser tooling should not hard-code a temporary mod format that Phase 0 has not defined.
- Browser tooling and later platform work should build on the build pipeline and release flow established in Phase 0.
- AI-assisted development should not bypass the instruction model or validation gates established in Phase 0.
- Vision, wake word, and swarming should not proceed as primary investments before AI stabilization is complete.
- Visual programming should target the same runtime contracts as expert mod development.
- Enterprise-ready scenario work should follow, not precede, vendor-flexible AI pipeline design.

## Success Measures

The roadmap should be reviewed against measurable outcomes, not only shipped features.

- Developer onboarding:
  - first successful firmware flash from a supported browser in under 10 minutes
  - first sample mod iteration without local SDK setup in under 15 minutes
- Runtime quality:
  - structured telemetry available for TTS failures
  - diagnostic scenarios that distinguish network, buffering, scheduling, and GC causes
- Platform extensibility:
  - documented contracts for mod packaging, logs, and AI adapters
  - provider changes that mostly avoid application-level rewrites
- AI-driven development:
  - repository-level conventions exist for `Skills`, `AGENTS.md`, and autonomous task boundaries
  - autonomous changes are gated by `xst` and TypeScript checks
- Ecosystem growth:
  - browser tooling for faces and simple behaviors built on top of the same platform primitives

## Items Deferred Until Core Stability Exists

The following are valuable, but should remain explicitly deferred unless prerequisites are met:

- Full wasm simulator parity with device runtime
- Production-grade swarming for many devices
- Enterprise-ready and multilingual deployment packages
- Broad educational tooling rollout beyond prototype scope

## Review Cadence

- End of May 2026: architecture and baseline review
- End of August 2026: browser-first MVP review
- End of October 2026: AI stabilization review
- End of December 2026: pluggable AI platform review
- End of March 2027: ecosystem tooling review

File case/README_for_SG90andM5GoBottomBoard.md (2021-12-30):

# Stack-chan case for SG90
[日本語](./README_for_SG90andM5GoBottomBoard_ja) | English
# Notice

The dimensions of the M5Stack's board are different from those of the Stack-Chan board, so the Stack Chan board cannot be used for this model.

# Appearance
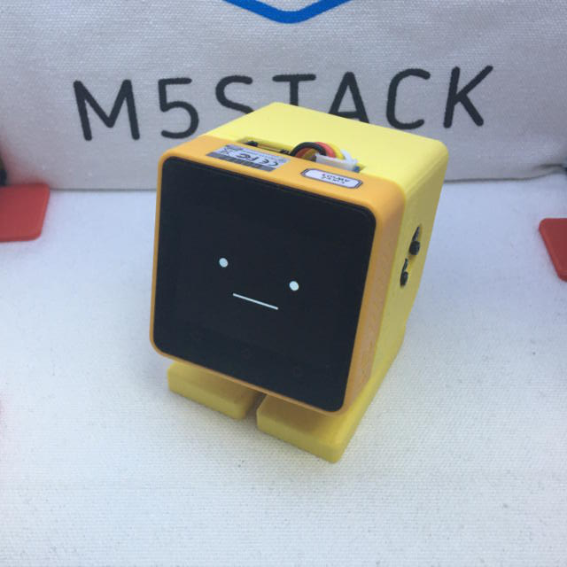
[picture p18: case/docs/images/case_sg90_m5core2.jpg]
case_sg90_m5core2

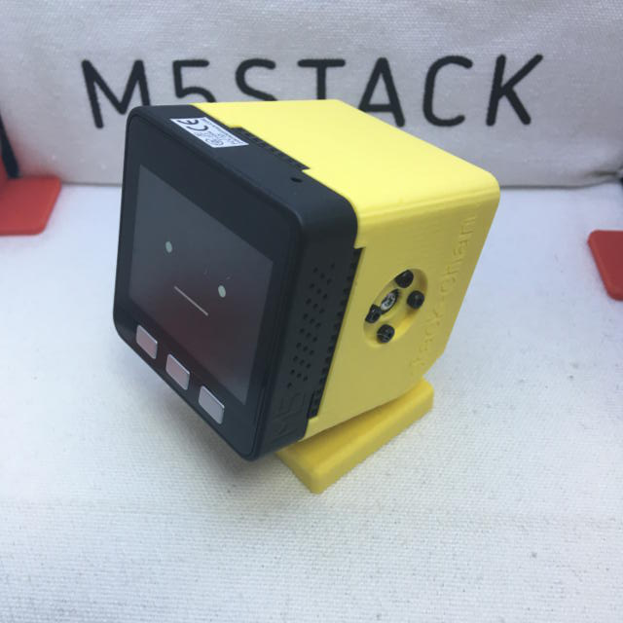
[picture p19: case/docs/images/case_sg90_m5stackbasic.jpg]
case_sg90_m5stackbasic


Currently the [case data](./case_for_SG90andM5GoBottomBoard/) is developed with Fusion360 and modified with DesighSparkMechanical.

## Things to prepare

### Parts

* 3D-printed cases
  * Shell
  * Feet
  * Bracket( There are 2 types for SG90 or MG90S) 
* M5Stack Core Basic/Gray/Go/Fire(+M5GoBottom1) or M5Stack Core2(+ M5Bottom2)
  * Recommended is [M5Stack Core2 for AWSIoT EduKit](https://shop.m5stack.com/collections/m5-controllers/products/m5stack-core2-esp32-iot-development) -AWSIoT EduKit is equipped with M5GoBottom2.
  * If you want to combine with M5Stack Basic/Gray/Go/Fire, you need [Power Switch for M5Stack](https://www.switch-science.com/catalog/5726/) and [Case](https://www.switch-science.com/catalog/6295/) is recommended. Since the power cannot be cut off, it will accelerate the deterioration of the battery.

* Two servos
  * Currently available on:
    * SG-90 pwm servo<br>Recommended is [M5Stack Servo Kit 180°](https://shop.m5stack.com/collections/m5-accessories/products/servo-kit-180), which has a shorter cable length.

* Screws
  * M2Bolt 5mm * 8pcs 
  * Screws included with the Servo(2 set)
    * 2mm screws 4pcs
    * 1.6?mm screws 2pcs
  * for M5GoBottom
    * M3 18mm * 2pcs
    * M3 15mm * 2pcs(for M5Stack Core2 only)
* Cable
  * [Grove - Branch Cable for Servo(5PCs pack)](https://www.seeedstudio.com/Grove-Branch-Cable-for-Servo-5PCs-pack.html)
  * Zip ties

### Tools
  * Precision screwdrivers
  * Hex key wrench (1.5mm and 2.5mm)
  * Cutting nippers

## Machining the parts

### Cut the servo horn of SG90.
Cut the cross-shaped servo horn with nippers at the third hole.<br>
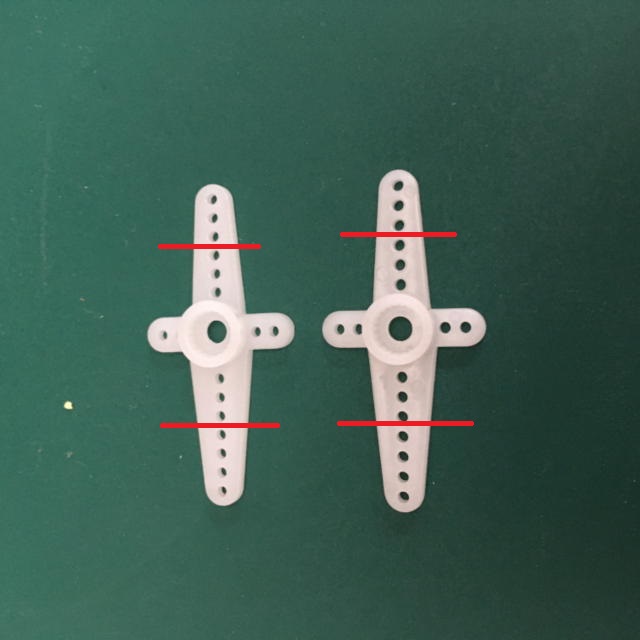
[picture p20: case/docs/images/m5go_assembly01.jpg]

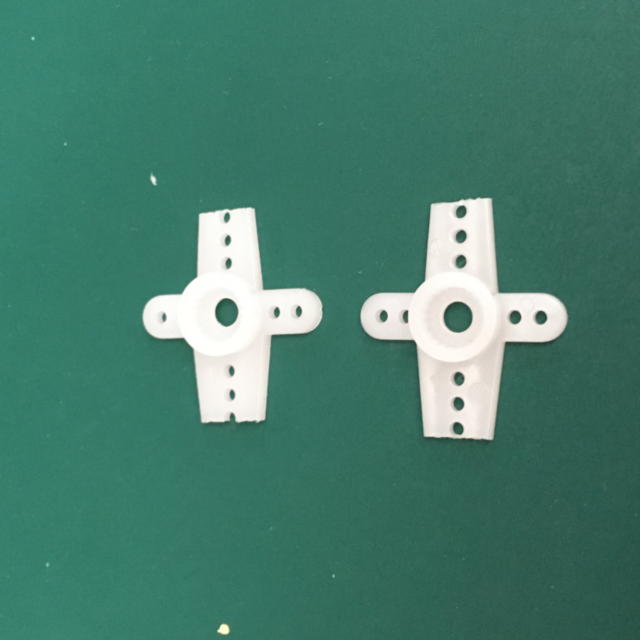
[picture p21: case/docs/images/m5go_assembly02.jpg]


### Removing the M5GoBottom board

Remove the screws from the four corners and remove the board. After removal, secure the battery by applying scotch tape. <br>

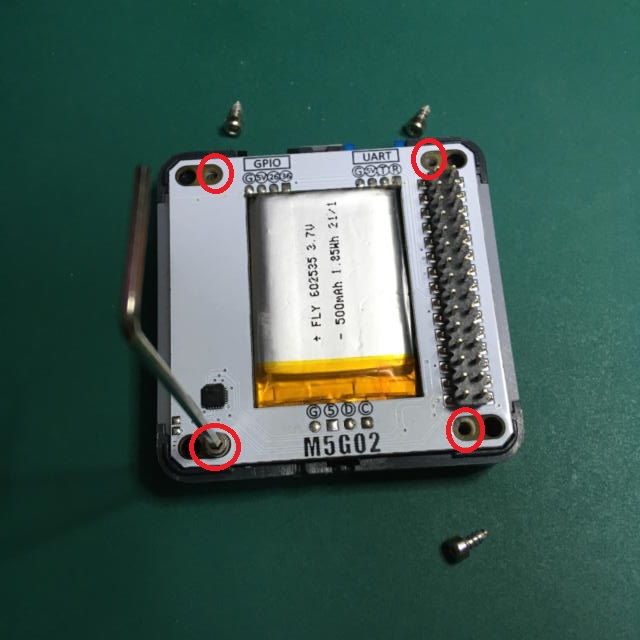
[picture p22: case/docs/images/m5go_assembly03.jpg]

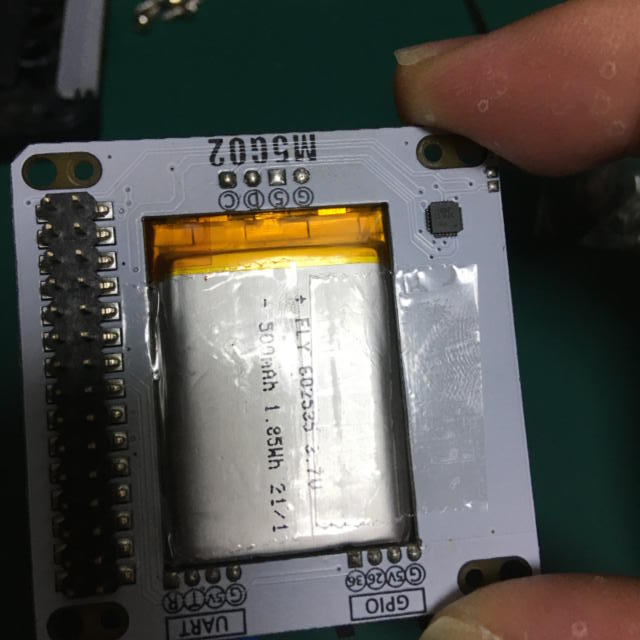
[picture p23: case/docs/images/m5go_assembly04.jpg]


### Bundle cables
Use Zip ties to bundle the servo branch cables.<br>
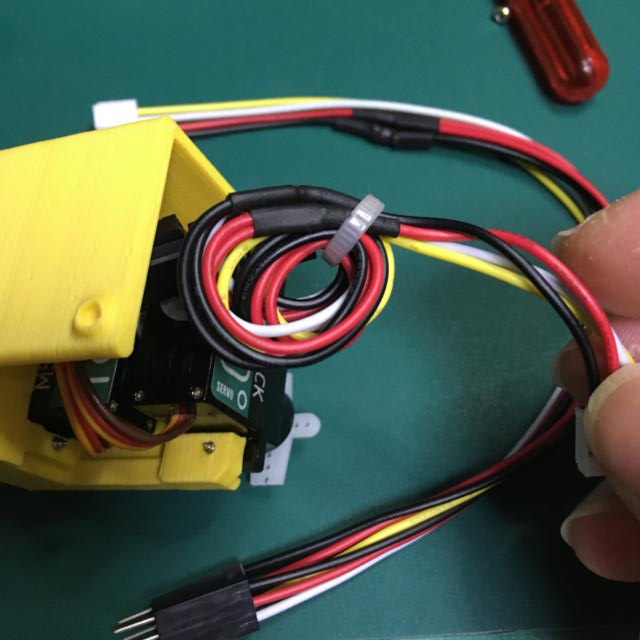
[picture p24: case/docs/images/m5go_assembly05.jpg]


## How to assemble

### 1. Attach the servos to the bracket.
Attach the servo to the bracket. Use the screws provided with the servo to secure it. Do not overtighten.<br>

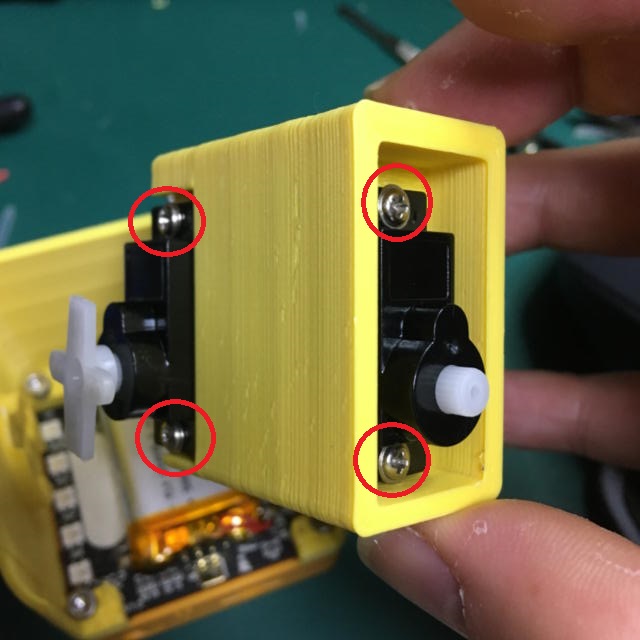
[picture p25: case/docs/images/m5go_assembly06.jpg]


### 2. Fix the servo horns.

Secure the servo horn to the case and foot using M1.6 bolts. <br>
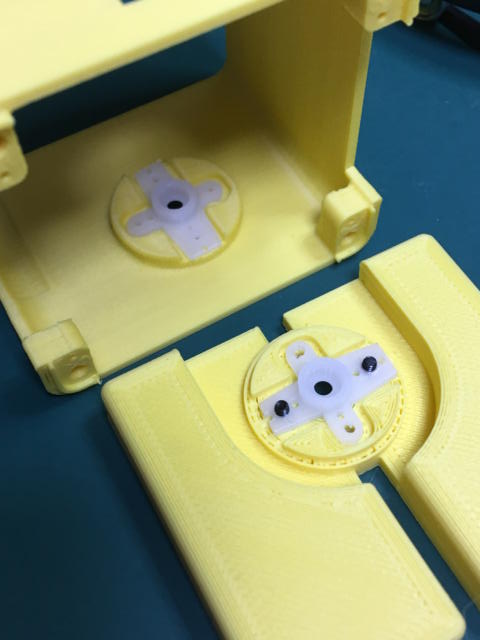
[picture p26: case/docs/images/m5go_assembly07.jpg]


### 3. Installing the board and case
If using Port.C, plug in the Grove cable first.
Using the small screws removed from the M5GoBottom, fix the M5GoBottom board to the case. After that, install the M5Stack and secure it with M3 bolts. (Be careful not to use the wrong length.)

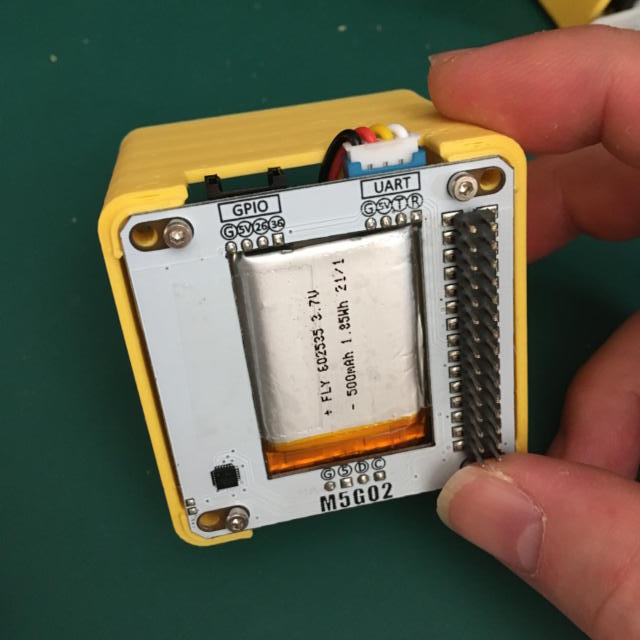
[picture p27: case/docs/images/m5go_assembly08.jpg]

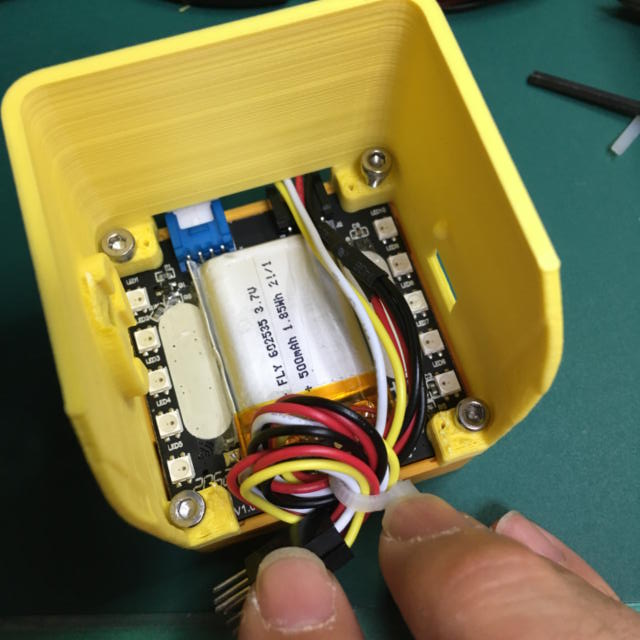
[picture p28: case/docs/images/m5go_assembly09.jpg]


### 4. Connecting

Connect the servo 2-branch cable to the servo connector. The application for operation check is set to use the following pins. <br> 
1. Port.C(GND,5V,G13,G14) of M5Stack Core2
- GPIO13 - Servo for pan (horizontal direction)
- GPIO14 - Tilt (vertical) servo

2. Port.C(GND,5V,G16,G17) of M5Stack (Basic/Gray/Go) 
- GPIO16 - Servo for pan (horizontal direction)
- GPIO17 - Servo for tilt (vertical direction)

3. Port.A(GND,5V,G21,G22) of M5Stack Fire
※1 Port.C cannot be used because it conflicts with PSRAM.
※2 Port.A is shared with internal I2C, so I2C and servo cannot be used simultaneously.
- GPIO21 - Servo for pan (horizontal direction)
- GPIO22 - Servo for tilt (vertical direction)

### 5. Assemble
With the servo at 90°, attach the legs and case to the bracket and secure it with the short screws provided with the servo. Store the small, two-branch cable in the bracket. <br>

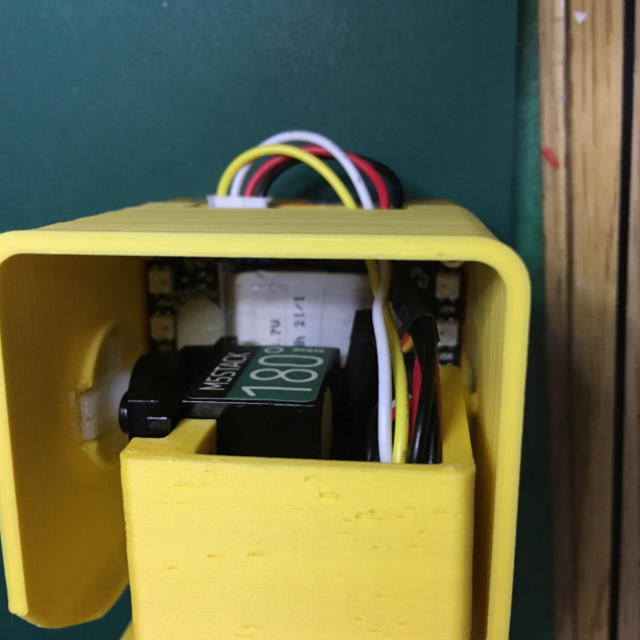
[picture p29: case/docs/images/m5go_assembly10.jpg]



# About MG90S
For the MG90S, we have published a bracket that matches the stock one. However, please be aware of the following problems.

1. power supply is not enough. <br>MG90S may not run on the M5Stack's internal battery alone. In that case, you will need to secure a separate power supply for the servos.

1. Some of the imitations on Amazon and AliExpress have different sizes. <br>Some of them are sold as MG90S, but the dimensions are the same as SG90 and the servo horns are different in size. In particular, if the servo horn is different, it will not fit the SG90 version either, in which case you will need to modify the model for the horn part.

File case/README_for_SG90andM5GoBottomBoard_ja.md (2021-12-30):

# Stack-chan case for SG90 and M5GoBottom
日本語 | [English](./README_for_SG90andM5GoBottomBoard.md)

# 注意事項
M5Stackの基板はｽﾀｯｸﾁｬﾝ基板とは寸法が異なるので、ｽﾀｯｸﾁｬﾝ基板はこちらのモデルには使用できません。

# 外観




[case data](./case_for_SG90andM5GoBottomBoard/)はFusion360で作成され、DesignSparkMechanicalで修正しました。

## 用意するもの

### 部品

* 3Dプリンタの出力品
  * シェル
  * 足
  * ブラケット(SG90とMG90Sの2種類あります。)
* M5Stack Core Basic/Gray/Go/Fire(+M5GoBottom1) M5Stack Core2(+ M5GoBottom2)
  * 推奨は[M5Stack Core2 for AWSIoT EduKit](https://shop.m5stack.com/collections/m5-controllers/products/m5stack-core2-esp32-iot-development-kit-for-aws-iot-edukit)です。AWSIoT EduKitにはM5GoBottom2が装備されています。
  * M5Stack Basic/Gray/Go/Fireと組み合わせる場合は[Power Switch for M5Stack](https://www.switch-science.com/catalog/5726/)及び[ケース](https://www.switch-science.com/catalog/6295/)の装着をおススメします。電源が切れないのでバッテリーの劣化を早めてしまいます。

* サーボ 2個
  * 対応しているサーボは下記のとおりです。
    * SG-90 pwm servo<br>ケーブルの長さが短い[M5Stack Servo Kit 180°](https://shop.m5stack.com/collections/m5-accessories/products/servo-kit-180)がおススメです。

* ネジやボルト
  * M1.6 5mm * 8個 
  * SG90付属 2mmネジ 4個 1.6mm?ネジ 2個
  * M5GoBottom固定用ボルト(M5Stack Core2 for AWSIoT EduKitに付属)
    * M3 18mm * 2個
    * M3 15mm * 2個(for M5Stack Core2 only)
* ケーブル
  * [GROVE - サーボ用2分岐ケーブル (5本セット)](https://www.switch-science.com/catalog/1250/)
  * ケーブルタイ

### 工具
  * 精密ドライバセット（プラスドライバ）
  * 六角レンチ（1.5mmと2.5mm）
  * ニッパー

## 部品の加工

### SG90 の十字サーボホーンをカット
十字の長いを3つ穴を残してニッパーで切断します。<br>



### M5GoBottomのボードを取り外す
四隅のネジを外して基板を外してください。取り外した後、バッテリーをセロハンテープで固定します。<br>



### Grove-サーボ2分岐ケーブルをまとめる。
ケーブルタイを使って小さくまとめます。<br>


## 組み立て

### ①ブラケットにサーボを付ける
ブラケットにサーボを取り付けます。固定はサーボ付属のネジを使ってください。締めすぎないように注意してください。



### ②サーボホーンの取り付け
ケースと足にM1.6のボルトを使ってサーボホーンを固定します。<br>


### ③ボードとケースの取り付け
Port.Cを使う場合は先にGroveケーブルを差し込んでおきます。
M5GoBottomから取り外した小さいネジを使い、ケースにM5GoBottom基板を固定します。その後、M5Stackを取り付けM3ボルトで固定します。（長さを間違えないように注意）<br>




### ④接続
サーボ2分岐ケーブルとサーボコネクタを接続します。動作確認用のアプリは下記のピンを使用するように設定してあります。<br>
1. M5Stack Core2のPort.C(GND,5V,G13,G14)
- GPIO13 - パン（水平方向）のサーボ
- GPIO14 - チルト（垂直方向）のサーボ

2. M5Stack (Basic/Gray/Go)のPort.C(GND,5V,G16,G17) 
- GPIO16 - パン（水平方向）のサーボ
- GPIO17 - チルト（垂直方向）のサーボ

3. M5Stack Fire Port.A(GND,5V,G21,G22)
※１ Port.CはPSRAMと競合するため使用できません。
※２ Port.Aは内部I2Cと共用のためI2Cとサーボの同時利用できません。
- GPIO21 - パン（水平方向）のサーボ
- GPIO22 - チルト（垂直方向）のサーボ

#サーボを90°にした状態で、ブラケットに足とケースを取り付けてサーボ付属の短いネジで固定します。小さくまとめた2分岐ケーブルをブラケットに収納します。<br>
## ⑤組み立て




# MG90Sについて
 MG90Sについては純正品に合わせたブラケットを公開してあります。しかし下記の問題があるため注意してください。

1. 電源が足りない。<br>MG90SはM5Stackの内部バッテリーだけでは動かない場合があります。その際は、サーボ用の電源を別で確保する必要があります。
1. AmazonやAliExpressでの模倣品の中にサイズが違うものがあります。<br>MG90Sとして売っていますが、寸法がSG90と同じものやサーボホーンの大きさが違うものがあります。特にサーボホーンが違うとSG90版とも合わないのでその場合はホーン部分のモデルを修正する必要があります。

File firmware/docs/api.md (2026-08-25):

# API

[日本語](./api_ja.md)

The detailed API document is under construction.

Stack-chan firmware sources include `TSDoc` style comments.
The repository keeps `firmware/tsconfig.json` for Node-side checks and API document generation.

Generate documents under `docs/api` by running:

```console
$ npm run generate-apidoc
```

## Architecture

Mods receive a `StackchanContext` capability object from `onContextCreated`.
The context exposes a small set of capabilities so UI, motion, speech, and input implementations can be replaced independently.

- [StackchanContext](#stackchancontext): Runtime capabilities passed to mods
- [RobotUI](#robotui): Controls the Piu application, face, effects, and drawer UI
- [Motion capability](#motion-capability): Controls neck pose and gaze movement through the public motion API
- [Audio capability](#audio-capability): Plays speech through the public audio API

// TODO: Capability diagram and description

## Coordinate system

coordinate for Stack-chan

Stack-chan's coordinate system is a **right-handed** system. When you bend your right hand's thumb, index finger, and middle finger so that they are perpendicular to each other, the thumb is the X-axis, the index finger is the Y-axis, and the middle finger is the Z-axis.

When Stack-chan's face is facing forward, the positive direction of each axis is as follows:

- Positive direction of X-axis... front of the face
- Positive direction of Y-axis... left side of the face
- Positive direction of Z-axis... head side

Also, the direction of rotation is the direction in which the right-hand screw advances in relation to the positive direction of the axis. In the case of Stack-chan's face, when rotating around each axis in the positive direction, it is as follows:

- Roll axis (rotation around X-axis) positive direction... Clockwise head tilt as seen from Stack-chan
- Pitch axis (rotation around Y-axis) positive direction... Stack-chan looking down
- Yaw axis (rotation around Z-axis) positive direction... Stack-chan looking to the left

In Stack-chan's API, **the unit of coordinates is meters and the unit of angles is radians**.
Correspondence with the coordinate system can also be referenced in the actual source code (e.g. [`mods/examples/look_around`](../mods/examples/look_around/) etc.).

## Public Types

### StackchanContext

`StackchanContext` exposes namespaced capabilities. New MODs should prefer these namespaces:

- `context.audio.say(...)`, `context.audio.record(...)`, `context.audio.playAudio(...)`
- `context.audio.useTTS(...)` for replacing the speech engine when a MOD owns that choice
- `context.motion.lookAt(...)`, `context.motion.setPose(...)`, `context.motion.setTorque(...)`
- `context.face.setEmotion(...)`, `context.face.setColor(...)`
- `context.i18n.locale`, `context.i18n.localize(...)`
- `context.ui.showBalloon(...)`, `context.ui.drawer.addDrawerButton(...)`
- `context.input.touch`, `context.input.touchPanel`, `context.input.imu`
- `context.lighting.lightOn(...)`, `context.camera.capture(...)`, `context.connectivity.network?.ready`, `context.connectivity.localPeer`
- `context.lifecycle.close()` for releasing runtime-owned timers, sensors, camera sessions, and motion timers

Input devices are optional. `context.input.touch` is defined only when the platform exposes `config.Touch`,
and `context.input.touchPanel` is defined only when the platform exposes `config.TouchPanel`.
MODs must check for `undefined` before attaching touch handlers.

`context.connectivity.network?.ready` resolves to `connected`, `skipped`, or `failed`.
Network-dependent MODs can await it and handle `skipped` or `failed` without importing host-internal network modules.
Local peer sessions support ESP-NOW and BLE Serial through the same API; see [Local peer messaging](./local-peer-communication.md).

`options.tail` in `context.ui.showBalloon(text, options)` accepts `top-left`, `top-right`, `bottom-left`, or
`bottom-right`. When omitted, bottom placement uses `top-left`, while an explicit `top` position uses
`bottom-left`.

Use `context.i18n.localize(key, values?)` for text shown by a MOD Drawer Button or Piu `Label`.
It resolves the MOD catalog first, then the host catalog, and finally the key itself.
See [Firmware localization](./localization.md) for catalog setup.

The legacy flat methods such as `context.say(...)`, `context.lookAt(...)`, `context.showBalloon(...)`, and `context.useTTS(...)` remain as compatibility shims for existing MODs.
They are deprecated for new code and may be removed after the sample MODs and downstream MODs have moved to the namespaced API.

### Lifecycle and errors

Runtime resources use `close()` as the release verb.
`close()` is idempotent, and the app runtime closes owned timers, sensors, camera sessions, and motion timers in that order.
`dispose()` is not used for firmware runtime resources.
`pause()` and `resume()` are operation-specific methods, not ownership release methods.

Optional hardware capabilities are represented as `undefined` when the platform does not provide the device.
For example, `context.input.touch`, `context.input.touchPanel`, `context.input.imu`, and `context.connectivity.network` are optional.
Required operations that cannot run on the current target throw or reject.
For example, `context.audio.record()` rejects when no microphone is available.
Supported operations with an expected unsupported result return a typed value instead of throwing.
For example, `context.audio.playAudio(buffer)` returns `false` when borrowed-buffer playback is unsupported or fails.

`Maybe<T>` is used only for user-facing operations that already surface a recoverable reason to UI or MOD code.
Promises reject for failed asynchronous commands where the caller needs control flow.
Synchronous argument errors throw.
`trace(...)` may add diagnostics, but it must not be the only failure signal for public capability operations.

The wasm audio bridge is the only current public-capability implementation that polls an asynchronous host operation.
Its 50ms interval is declared as `WASM_AUDIO_BRIDGE_POLL_INTERVAL_MS` in the bridge contract and is limited to browser audio record/play status checks.

### RobotUI

`RobotUI` is the UI capability namespace exposed as `context.ui`.
It provides face/effect operations, drawer registration, and drawer open/close methods without requiring MODs to reach through `ui.application`.

### Motion capability

The public motion API exposes `pose`, `lookAt`, `lookAway`, `setPose`, and `setTorque`.
Low-level driver objects are internal to `host/modules/motion` and are not exposed to MODs.

### Audio capability

The public audio API exposes speech playback through the capability object passed to MODs.
Provider objects for local, remote, Voicevox, ElevenLabs, and OpenAI speech are internal to `host/modules/audio`.

`sing(koe, volume?)` plays stackchan-voice singing notation when the active TTS provider supports it.
It returns a failed result for providers without singing support; it never sends the notation to ordinary speech synthesis as text.

`playAudio(buffer)` returns `true` only when the target accepts the borrowed buffer and playback completes.
It returns `false` when the target does not support buffer playback, the buffer is empty, or playback fails.
Callers must keep ownership of the buffer and should treat `false` as an observable unsupported-or-not-played result.

- [Using Text To Speech(TTS)](./text-to-speech.md)
- [stackchan-voice speech and singing](./stackchan-voice.md)

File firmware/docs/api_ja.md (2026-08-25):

# API

[English](./api.md)

APIの詳しいドキュメントは現在作成中です。

ｽﾀｯｸﾁｬﾝのソースコードには `TSDoc` 形式のコメントがついています。
このリポジトリでは、Node.js 側の検査と API ドキュメント生成のために `firmware/tsconfig.json` を保持しています。

次のコマンドを実行すると、`docs/api` ディレクトリ配下にドキュメントを生成できます。

```console
$ npm run generate-apidoc
```

## 構成

MODは`onContextCreated`から`StackchanContext`を受け取ります。
`StackchanContext`は、UI、motion、speech、inputの実装を独立して差し替えられるように、少数のcapabilityを公開します。

- [StackchanContext](#stackchancontext): MODに渡されるruntime capabilityの集合
- [RobotUI](#robotui): Piu Application、顔、エフェクト、ドロワーUIの制御
- [Motion capability](#motion-capability): 公開 motion API による首姿勢と視線移動の制御
- [Audio capability](#audio-capability): 公開 audio API による音声再生

// TODO: capability図と説明

## 座標系

ｽﾀｯｸﾁｬﾝの座標系

ｽﾀｯｸﾁｬﾝの座標系は **右手系** です。
右手の親指、人差し指と中指がそれぞれ直行するように曲げたとき、
親指がX軸、人差し指がY軸、中指がZ軸となります。

ｽﾀｯｸﾁｬﾝの顔が正面を向いているとき、各軸の正の方向は次のとおりです。

- X軸の正方向…顔の前側
- Y軸の正方向…顔の左側
- Z軸の正方向…頭側

また、回転の向きは軸の正の方向に対して右ねじが進む向きとなります。
ｽﾀｯｸﾁｬﾝの顔でいうと、各軸の周りを正の方向へ回転する場合次のようになります。

- ロール軸（X軸まわりの回転）の正方向…ｽﾀｯｸﾁｬﾝから見て時計回りに首をかしげる動き
- ピッチ軸（Y軸まわりの回転）の正方向…ｽﾀｯｸﾁｬﾝが下を向く動き
- ヨー軸（Z軸まわりの回転）の正方向…ｽﾀｯｸﾁｬﾝが左を向く動き

ｽﾀｯｸﾁｬﾝのAPIにおいては **座標の単位はメートル、角度の単位はラジアンになります** 。
座標系との対応は実際のソースコード（[`mods/examples/look_around`](../mods/examples/look_around/)など）も参考にしてください。

## 型

### StackchanContext

`StackchanContext` は namespaced capability を公開します。
新しい MOD では次の形式を推奨します。
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

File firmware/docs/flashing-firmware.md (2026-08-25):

## Build and flash firmware

[日本語](./flashing-firmware_ja.md)

## Firmware architecture

### Host and MOD

firmware architecture

Stack-chan's firmware consists of a program that provide the basic operation of Stack-chan (host), and a user application (mod).
Once the host is written, the mod can be installed in a short time for fast development.
First write the host, and then write the mods as needed.
When no MOD is installed, the host runs the product default behavior.
When a MOD is installed, that MOD replaces the product default behavior and receives the runtime context through `onContextCreated`.
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

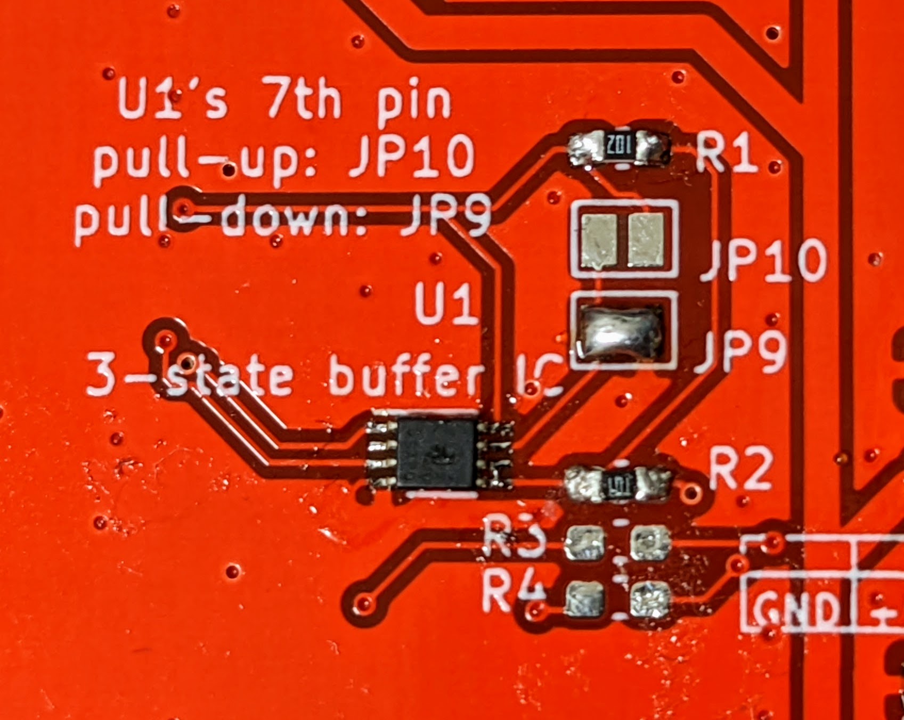
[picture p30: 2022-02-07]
schematics/docs/images/serial_ic.jpg

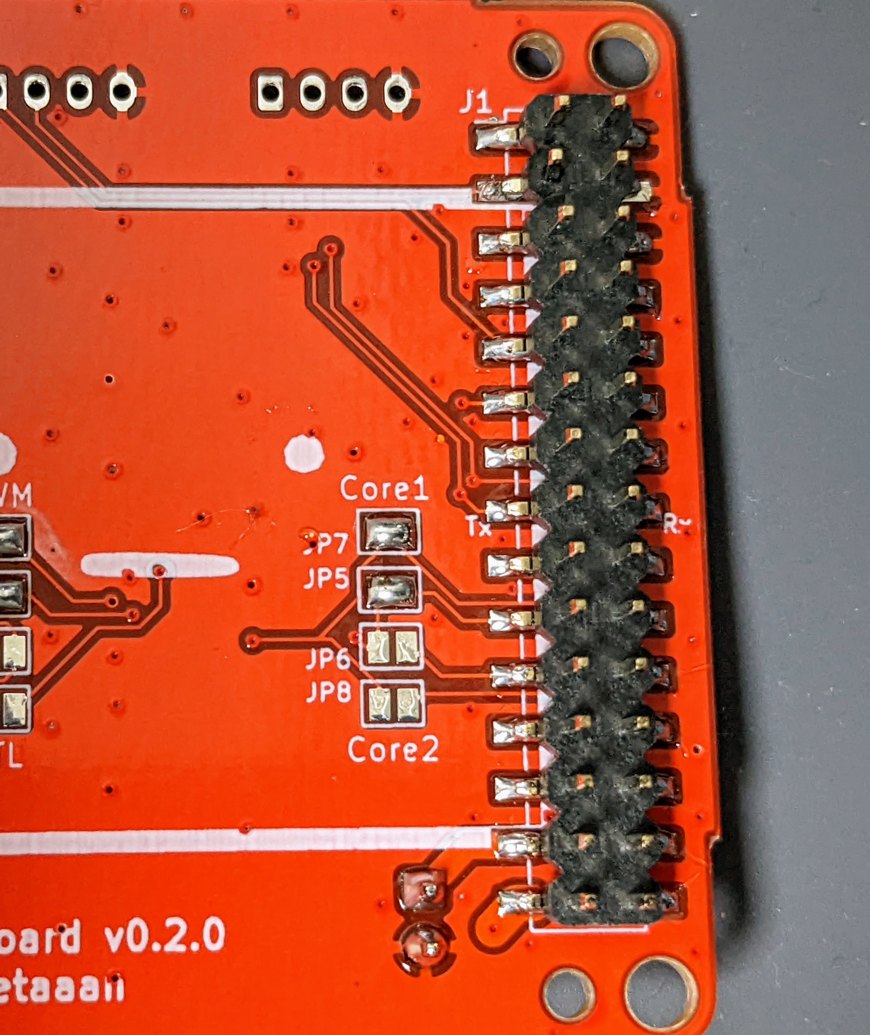
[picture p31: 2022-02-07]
schematics/docs/images/pwm_2x15.jpg

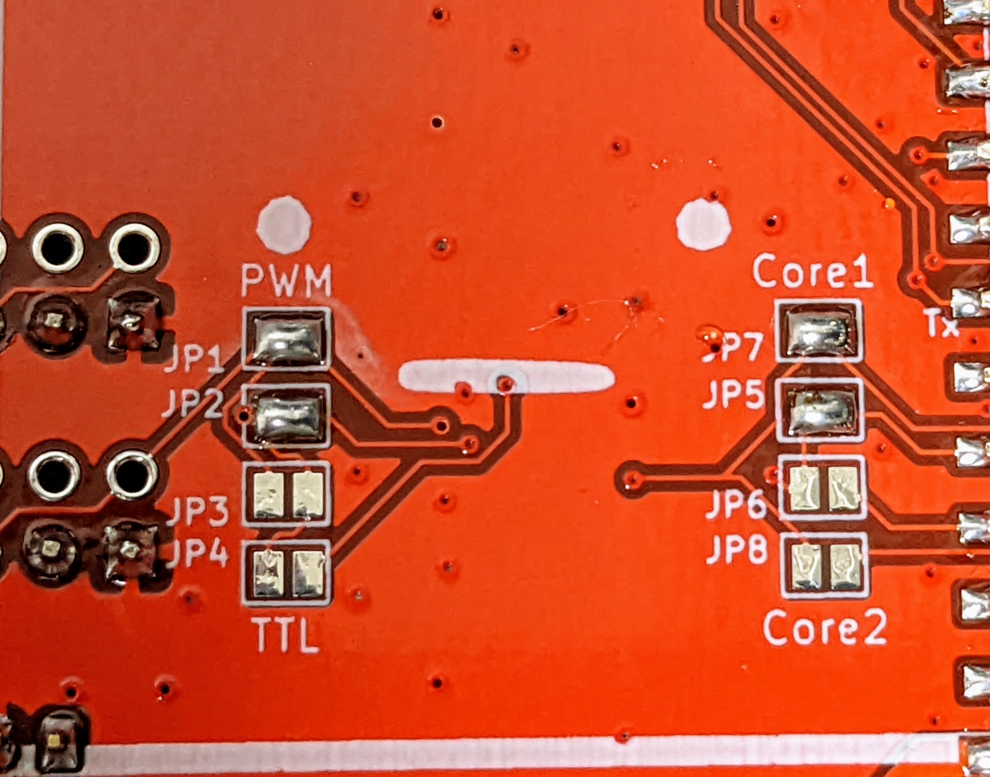
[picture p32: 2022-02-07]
schematics/docs/images/pwm_jumper.jpg

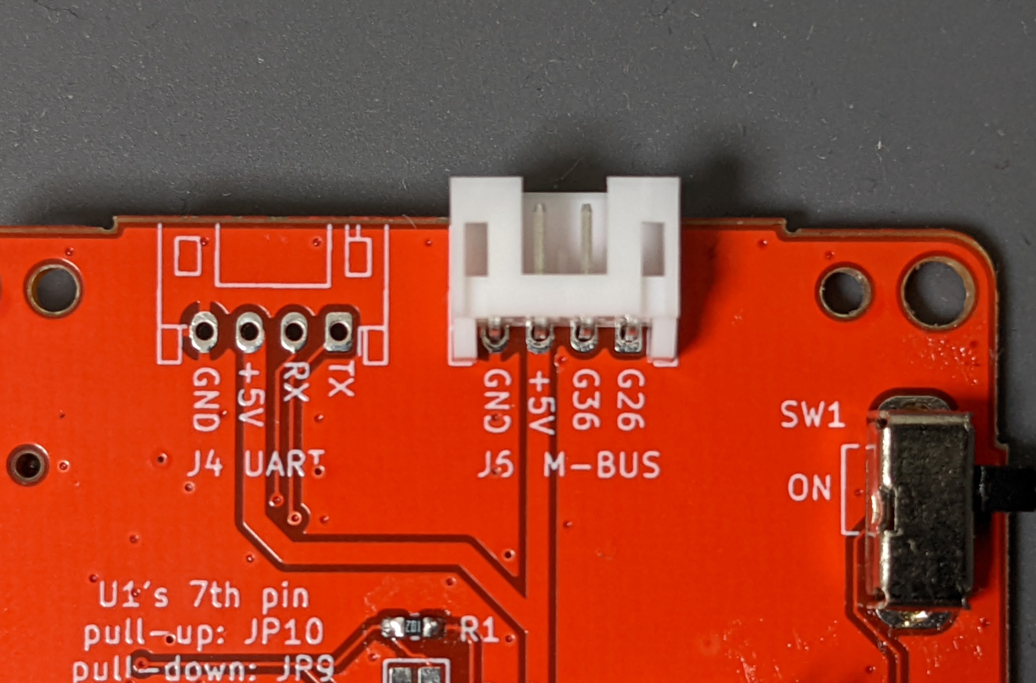
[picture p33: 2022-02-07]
schematics/docs/images/serial_ports.jpg

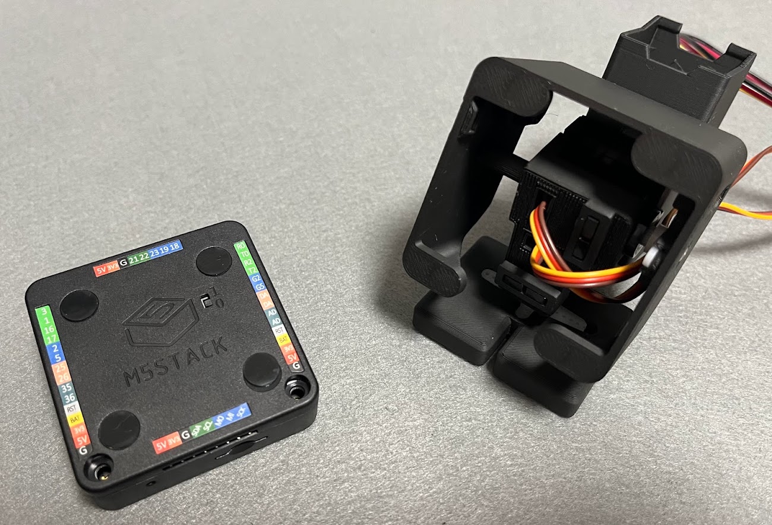
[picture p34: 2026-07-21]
case/contributed/magnet_shell_basic_v2.7_SG90/docs/images/overview.jpg

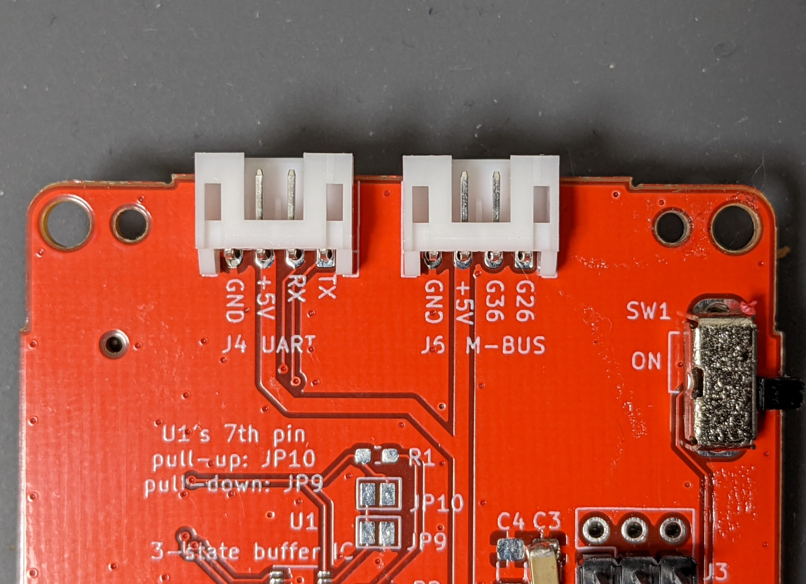
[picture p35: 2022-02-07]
schematics/docs/images/pwm_ports.jpg

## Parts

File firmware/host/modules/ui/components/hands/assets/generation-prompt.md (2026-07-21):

# Image generation prompt

The source sheet was generated with the built-in image generation tool using
this prompt:

```text
Use case: stylized-concept
Asset type: a production-oriented 2D UI hand sprite-sheet concept for a tiny embedded robot face display

Primary request: Create EXACTLY 32 separate floating cartoon RIGHT-HAND sprites arranged in a precise 4-row by 8-column grid. Each sprite is a naturally redrawn directional pose, not merely the identical shape mechanically rotated.

Grid semantics:
- Columns, from left to right: gesture upward, upper-right, right, lower-right, downward, lower-left, left, upper-left.
- The hand must naturally point, lean, spread, and pose toward each requested direction. Subtle changes of silhouette and posture between directions are desirable.
- Row 1: FIST. A cute closed fist shaped like an asymmetric rounded bean or soft squircle, with a subtly flatter knuckle side and a thumb-side bulge. Definitely not a perfect circle.
- Row 2: POINT. Only the thumb and index finger are visibly extended. The index finger clearly indicates the column direction. Make it unmistakably an index-pointing gesture, never resembling a raised middle finger. The thumb is thick, begins near the wrist side, and balances the silhouette. Other fingers are merged into the rounded palm.
- Row 3: PEACE SIGN. Two short, thick, blunt, rounded fingers make a clear V sign toward the column direction. The remaining fingers and tucked thumb merge simply into the palm.
- Row 4: OPEN HAND. One thick thumb plus exactly three short, thick, rounded long fingers. Cute four-digit cartoon hand, not anatomically five-fingered.

Style/medium: extremely simple flat two-color vector-like UI sprite art; playful and chubby; smooth confident silhouette; suitable for reduction to a small bitmap.
Color palette: outer silhouette and thick outline in solid deep navy #111827; inner region in solid white #FFFFFF.
Shape rules:
- Every hand must read as one connected outline shape.
- No internal separator lines between fingers and palm.
- Fingers are short, thick, nearly constant-width, with rounded tips and no narrow pinched roots.
- Thumb is especially thick and its root sits toward the wrist side.
- No arm, no forearm line, no cuff, no wrist stem. Each hand floats by itself.
- Closed clean bottom edge on the palm.
- Keep outline thickness visually consistent across all 32 sprites.
- Use the same design language, approximate scale, and palm-center anchor across every cell.

Composition/framing: exact 4 by 8 array; equal square cells; every hand centered in its cell with generous clear gutters; no sprite overlaps another; no cropping; no labels; no captions; no arrows; no row or column headers; no borders and no visible grid lines.

Scene/backdrop: perfectly flat solid #00FF00 chroma-key background for later background removal. The background must be one uniform exact color with no shadows, gradients, texture, reflections, floor plane, or lighting variation. Do not use #00FF00 anywhere in the sprites.

Constraints: exactly 32 hands, exactly four rows and eight columns; right-hand design consistently; purely flat colors; crisp edges; no lighting; no shading; no highlights; no 3D rendering; no texture; no facial features; no objects; no text; no watermark.
Avoid: realistic anatomy, skinny fingers, long fingers, fingernails, finger joints, internal palm lines, extra fingers, missing required fingers, disconnected parts, gloves with cuffs, arms, mechanical rotation-copy appearance.
```

## Side-open source

The side-open source was generated in built-in tool mode with
`hands-source-right.png` as a style reference. The selected source was then
edited once to make the eight screen-plane directions explicit. Its eight
sprites are stored as row 5 of the current `hands-source-right.png` authoring
sheet rather than as a separate runtime or source texture.

Initial generation prompt:

```text
Use case: stylized-concept
Asset type: 2D UI sprite sheet for a tiny robot display
Input image role: Image 1 is a style reference only. Match its simple navy outline, white interior, cute proportions, and flat vector-like finish. Create a new image containing only the new pose.

Create EXACTLY 8 separate floating cartoon glove icons in a single horizontal row of 8 equal cells. Every icon is the same RIGHT glove in a narrow side-facing clapping pose, like a soft rounded mitten viewed edge-on. It must not show the broad front face of an open glove.

Column directions, left to right: up, upper-right, right, lower-right, down, lower-left, left, upper-left. The direction describes where the rounded top of the glove points. Redraw each direction naturally while keeping one consistent design and scale.

Silhouette: narrow, compact, soft, and cute. The upper portion is one unified rounded lobe with only subtle shallow bumps along its outside edge. Add one modest rounded side bulge near the lower end to suggest the folded thumb. One connected outer silhouette per icon, with no interior detail lines.
Colors: solid deep navy #111827 outer silhouette and thick outline; solid white #FFFFFF inner region.
Background: perfectly uniform flat #00FF00 chroma-key green, with no shadow, gradient, texture, reflection, floor, or lighting variation. Never use green in an icon.
Layout: exactly one row and eight columns; consistent centers and size; generous gaps; no overlap, cropping, grid lines, labels, arrows, text, or watermark.
Do not include arms, cuffs, wrist stems, separated digits, spread-open poses, front-facing palms, fists, pointing signs, peace signs, realistic anatomy, fingernails, joints, objects, 3D rendering, shading, highlights, or extra marks.
```

Direction edit prompt:

```text
Use case: precise-object-edit
Asset type: 2D UI sprite sheet for a tiny robot display
Input image role: Image 1 is the EDIT TARGET.

Primary request: Keep the exact same eight side-facing cartoon glove designs, colors, outline style, single-row layout, scale, green background, and spacing. Change ONLY the orientation of each complete glove icon so the row becomes an eight-direction sprite set.

Required orientation by column, left to right:
1. point the glove's long rounded top straight UP (0 degrees)
2. point it UPPER-RIGHT (45 degrees clockwise)
3. point it RIGHT (90 degrees clockwise)
4. point it LOWER-RIGHT (135 degrees clockwise)
5. point it DOWN (180 degrees)
6. point it LOWER-LEFT (225 degrees clockwise)
7. point it LEFT (270 degrees clockwise)
8. point it UPPER-LEFT (315 degrees clockwise)

Rotate/repose the WHOLE glove silhouette in each cell, including the lower side bulge. The changing directions must be unmistakable. Preserve exactly 8 separate icons in one row, all fully visible and centered in equal conceptual cells with generous gaps.
Constraints: change only orientation; preserve the narrow edge-on clapping pose; perfectly flat uniform #00FF00 background; deep navy #111827 outline/outer silhouette and white fill; no grid, labels, arrows, text, shadows, shading, arms, cuffs, extra icons, or watermark.
```

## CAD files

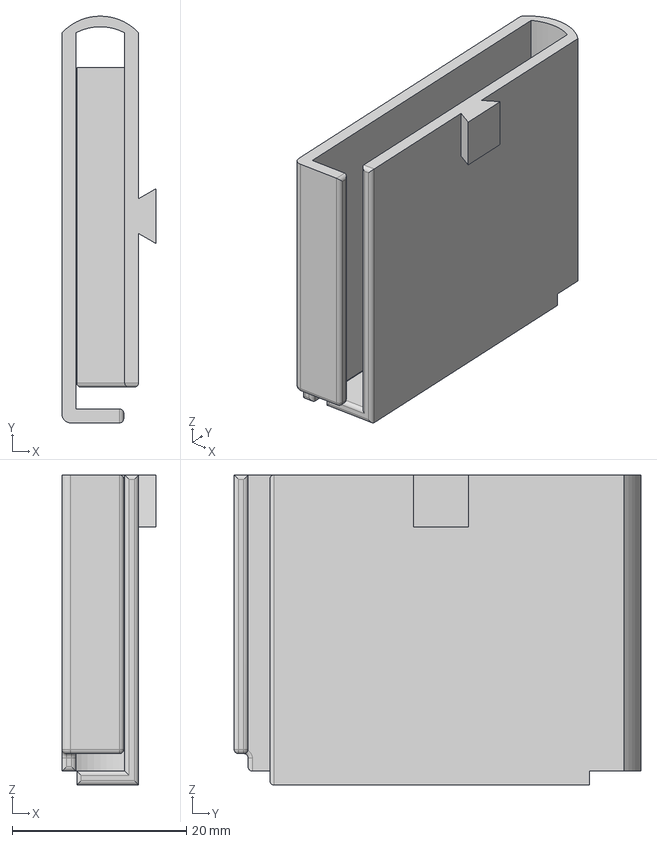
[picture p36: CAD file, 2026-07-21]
case/backpack/backpack_640mah.step
10.8 x 46.7 x 35.6 mm

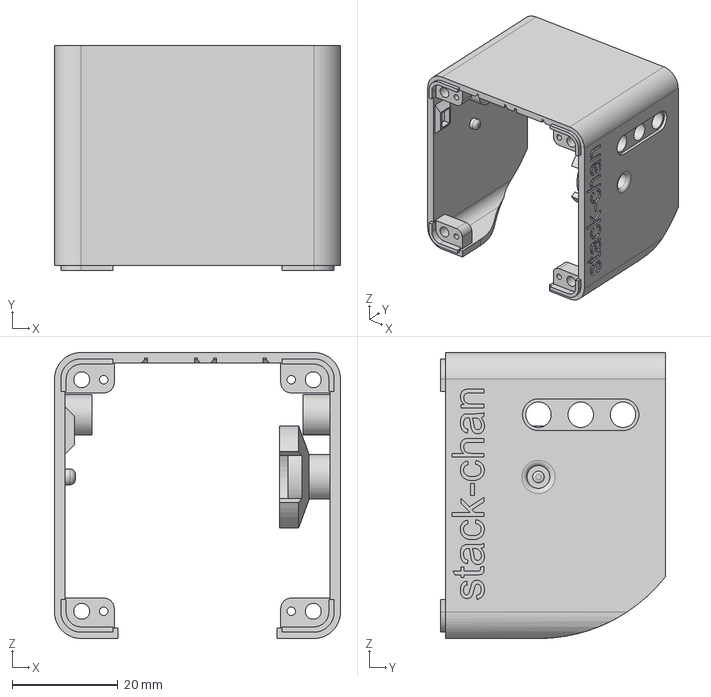
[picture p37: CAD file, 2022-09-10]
case/case_RS30X/shell_RS30X.step
54.0 x 42.5 x 54.0 mm

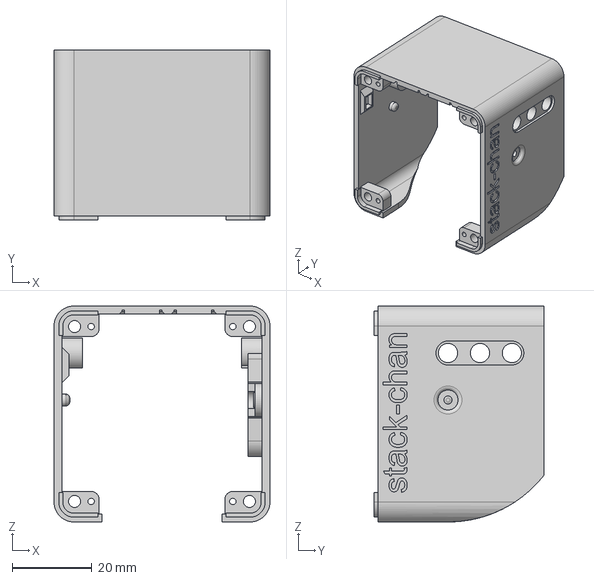
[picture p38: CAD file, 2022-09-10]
case/case_SCS0009/shell_SCS0009.step
54.0 x 42.5 x 54.0 mm

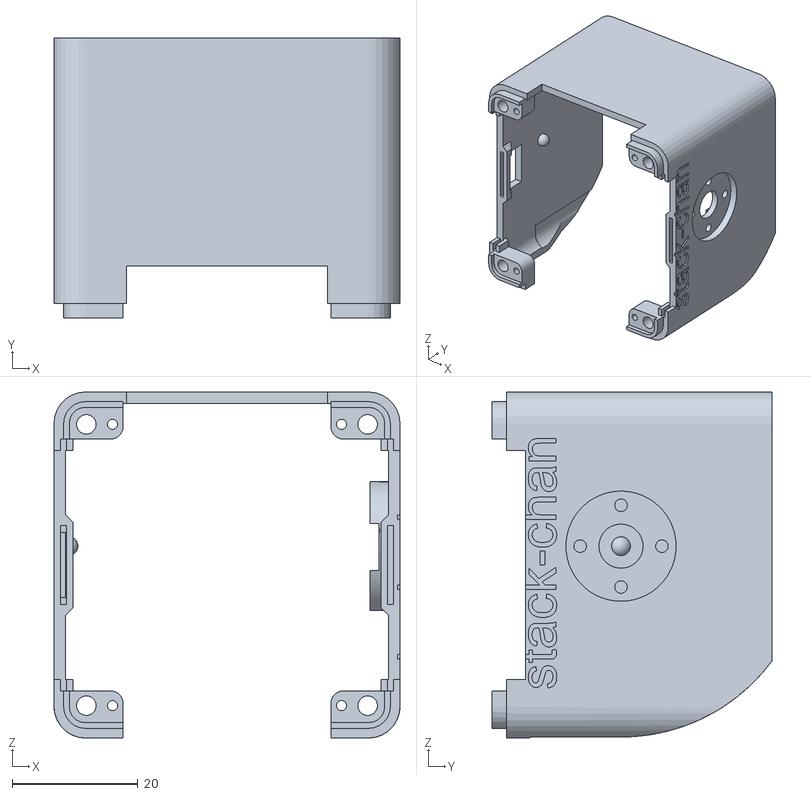
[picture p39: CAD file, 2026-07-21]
case/contributed/HS_Glide_Path_case for_SG90_and_M5Stack_AWS/case_for_SG90andM5StackAWS/shell_SG90_AWS_LED.stl
55.0 x 44.5 x 55.0

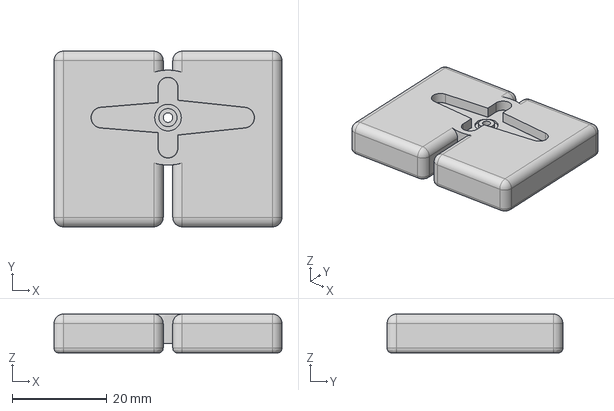
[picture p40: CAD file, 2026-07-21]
case/contributed/Magnetic_Case_Core2_AWS_SG90/feet_SG90.step
48.0 x 37.0 x 8.20 mm

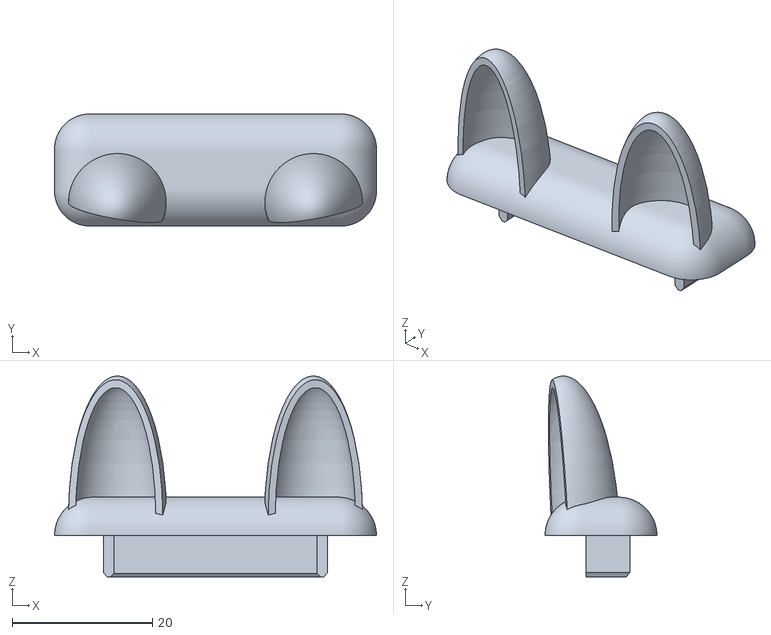
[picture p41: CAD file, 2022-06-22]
case/contributed/mongonta_case_for_SG90_and_M5GoBottomBoard/case_for_SG90andM5GoBottomBoard/Accessories_for_M5GoBottomShell/hat_cat_ear_v2.0.stl
46.0 x 16.0 x 28.7

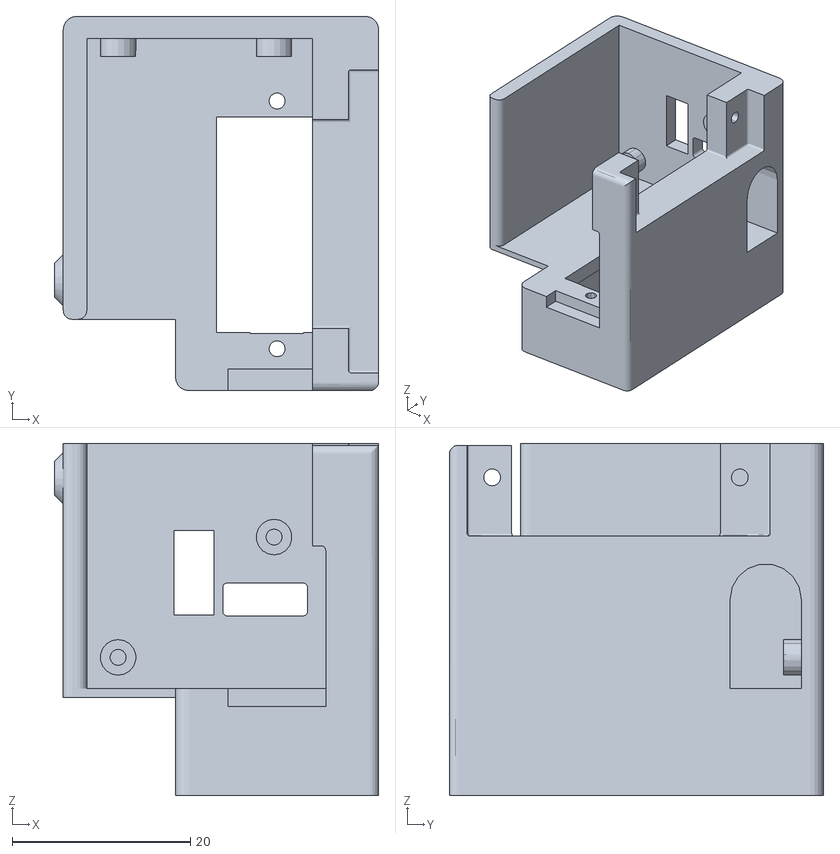
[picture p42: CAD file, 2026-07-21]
case/contributed/mongonta_case_for_SG90_and_M5GoBottomBoard/case_for_SG90andM5GoBottomBoard/bracket_SG90_v2.0.stl
36.4 x 42.0 x 39.5

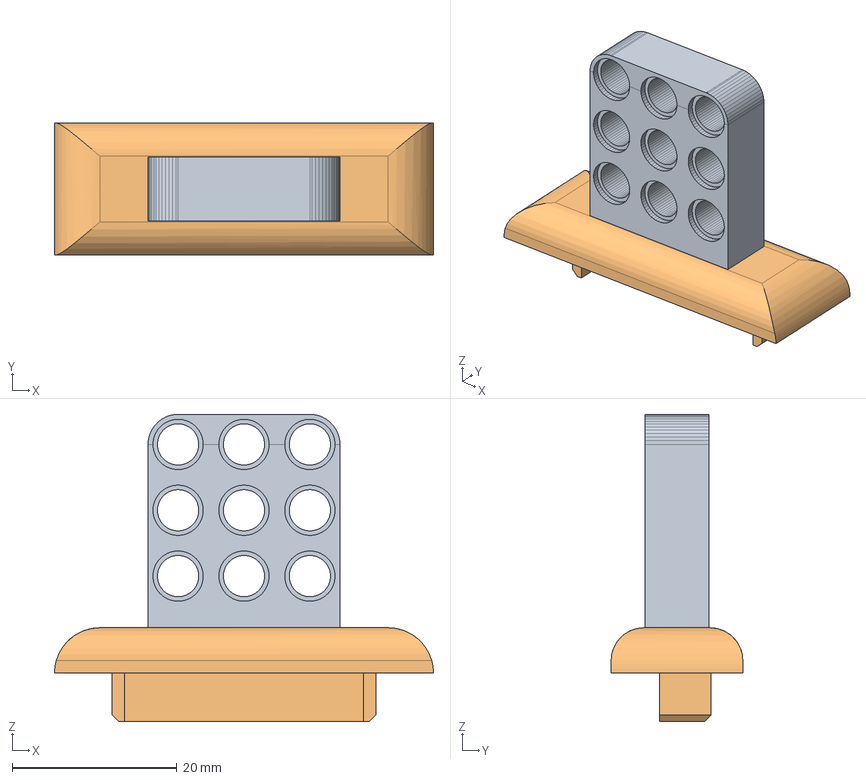
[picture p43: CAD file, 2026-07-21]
case/contributed/mongonta_case_for_SG90_and_M5GoBottomBoard/case_for_SG90andM5GoBottomBoard/step/Accesories_for_M5GoBottomShell/hat_lego_9hole_v1.0.stp
46.0 x 16.0 x 37.3 mm
head_adapter_lego_9hole.2
head_adapter_org.12

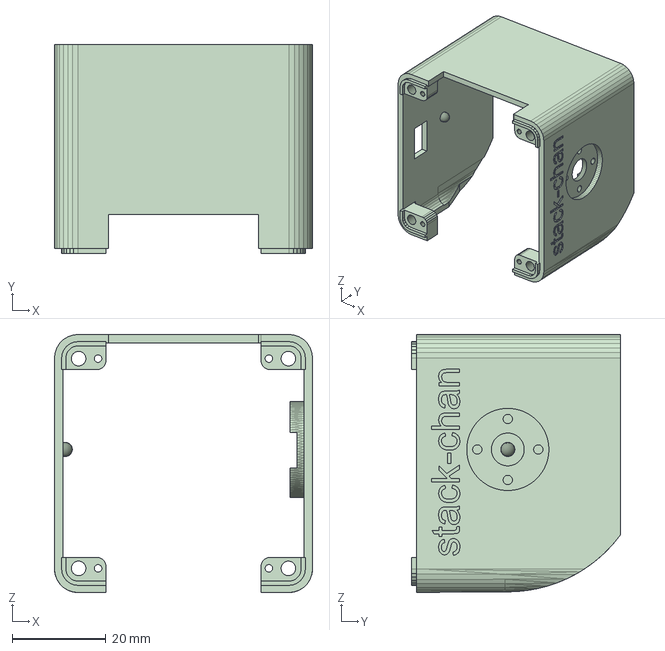
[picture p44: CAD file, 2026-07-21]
case/contributed/mongonta_case_for_SG90_and_M5GoBottomBoard/case_for_SG90andM5GoBottomBoard/step/shell_SG90_gobottom_v1.0.stp
55.0 x 44.5 x 55.0 mm

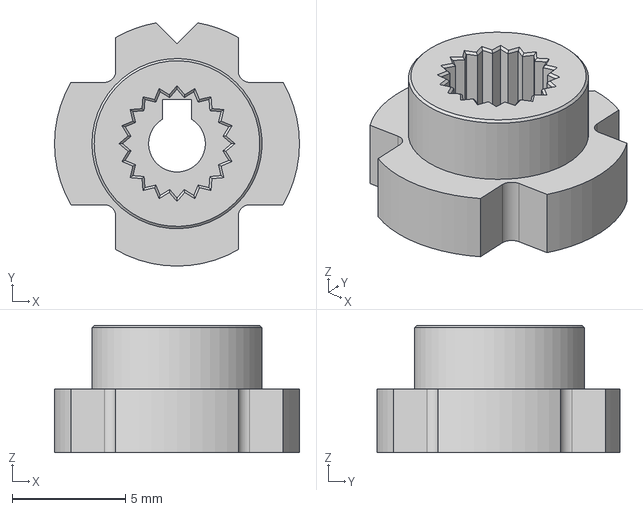
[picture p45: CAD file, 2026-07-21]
case/v1/gear_XL330_narrow.step
10.8 x 10.7 x 5.60 mm

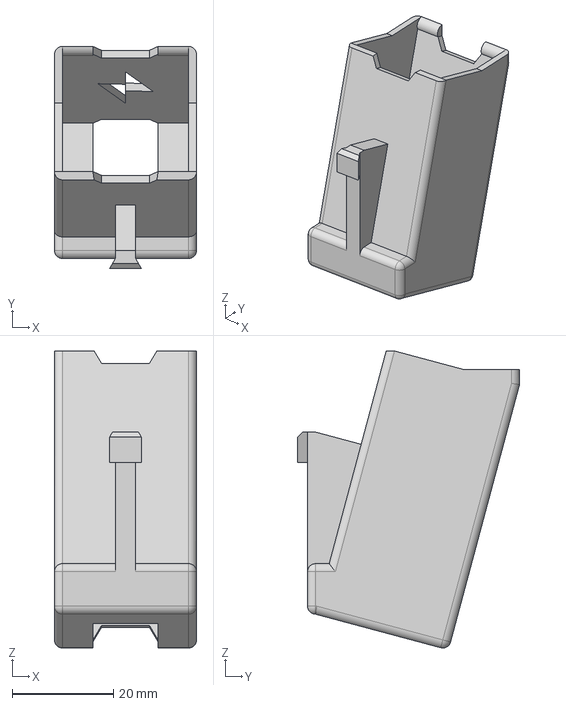
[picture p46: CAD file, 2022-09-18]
case/backpack/backpack_aaa.step
28.1 x 43.9 x 58.7 mm

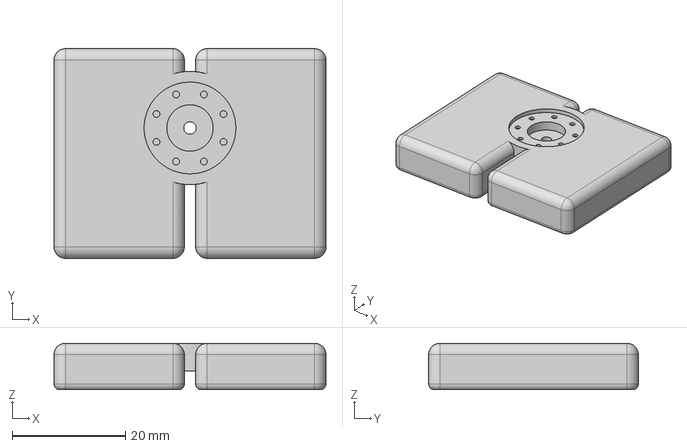
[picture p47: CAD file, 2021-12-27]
case/case_RS30X/feet_RS30X.step
48.0 x 37.0 x 8.20 mm

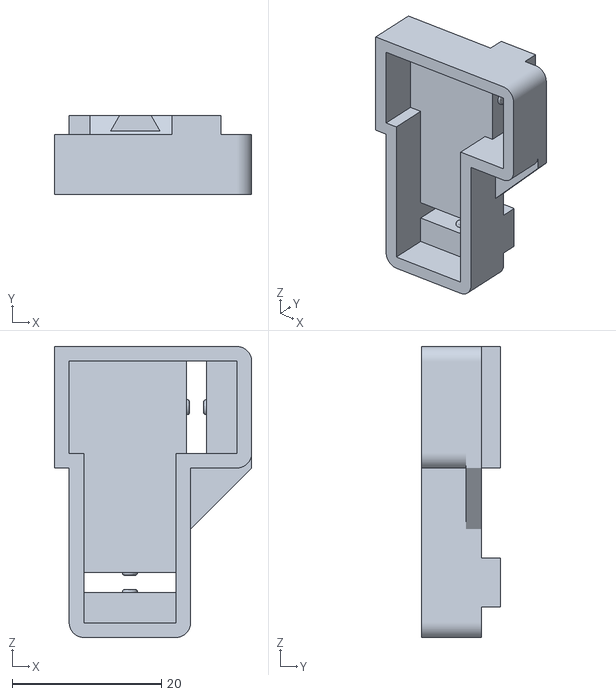
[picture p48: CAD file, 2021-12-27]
case/case_SG90/bracket_SG90_b.stl
26.5 x 10.7 x 39.1

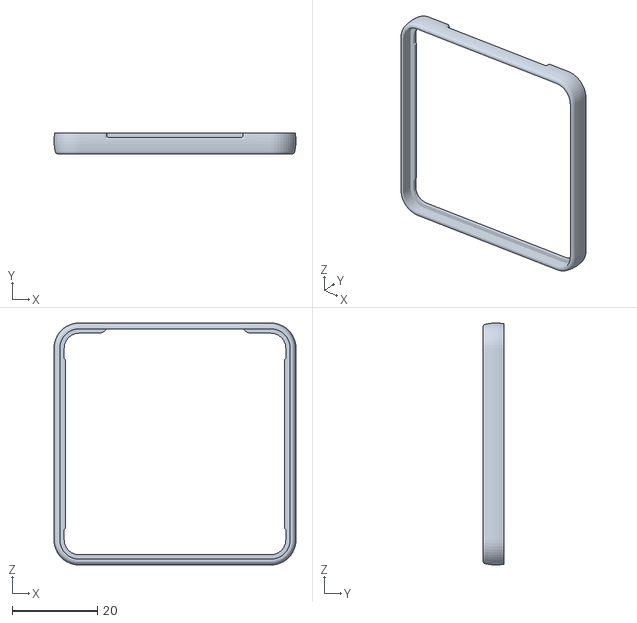
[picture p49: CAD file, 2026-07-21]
case/contributed/HS_Glide_Path_case for_SG90_and_M5Stack_AWS/case_for_SG90andM5StackAWS/spacer_for_AWS.stl
56.8 x 5.00 x 56.8

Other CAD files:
case/case_SG90/shell_SG90.step
case/contributed/magnet_shell_basic_v2.7_SG90/shell_SG90_magnet_basic_v2.7.step
web/simulator/assets/case/v1/shell.stl
case/case_SCS0009/feet_SCS0009.step
case/backpack/backpack_400mah.step
case/backpack/backpack_400mah.stl
case/backpack/backpack_640mah.stl
case/backpack/backpack_aaa.stl
case/backpack/backpack_casio_battery.step
case/backpack/backpack_casio_battery.stl
case/case_RS30X/bracket_RS30X.step
case/case_RS30X/bracket_RS30X.stl
case/case_RS30X/feet_RS30X.stl
case/case_RS30X/shell_RS30X.stl
case/case_SCS0009/bracket_SCS0009.step
case/case_SCS0009/bracket_SCS0009_b.stl
case/case_SCS0009/bracket_SCS0009_f.stl
case/case_SCS0009/feet_SCS0009.stl
case/case_SCS0009/shell_SCS0009.stl
case/case_SG90/bracket_SG90.step
case/case_SG90/bracket_SG90_f.stl
case/case_SG90/feet_SG90.step
case/case_SG90/feet_SG90.stl
case/case_SG90/shell_SG90.stl
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

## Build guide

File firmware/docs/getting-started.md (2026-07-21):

# Getting Started

[日本語](./getting-started_ja.md)

## Prerequisites

* Host PC（Windows/Mac/Linux）
    * Tested with environments below
        * Linux(Ubuntu24.04)
* M5Stack（Basic/Core2/CoreS3）
* USB type-C cable
* [git](https://git-scm.com/)
* [Node.js](https://nodejs.org/en/)
    * Tested with v22

## Clone the repository

Clone this repository.

```console
$ git clone https://github.com/stack-chan/stack-chan.git
$ cd stack-chan/firmware
$ npm i
```

## Setting up ModdableSDK

On the host PC, install [ModdableSDK](https://github.com/Moddable-OpenSource/moddable) and
Install [ESP-IDF](https://docs.espressif.com/projects/esp-idf/en/latest/esp32/get-started/index.html) on the host PC.
There are three ways to do this

- Using the CLI (recommended)
- Using a Docker image
- Set up manually

### Using xs-dev (recommended)

Stack-Chan has npm scripting of the setup procedure.
Run the following command in the `stack-chan/firmware` directory.

```console
$ npm run setup
$ npm run setup -- --device=esp32
```

The script internally uses [`xs-dev`](https://github.com/HipsterBrown/xs-dev) to automate the setup of ModdableSDK and ESP-IDF.

### Using Docker images (for Linux only)

This repository provides a Dockerfile build environment.
You can build, write and debug firmware inside a Docker container.

Note: This has been tested and confirmed to work on Linux (Ubuntu 24.04). It is not recommended for use on Windows (WSL) or MacOS, as there have been reported [issues](https://github.com/stack-chan/stack-chan/issues/144) with connecting to devices from the container side.

#### From terminal

Run the following command in the `stack-chan/firmware` directory.

```console
$ ./docker/build-container.sh
$ ./docker/launch-container.sh

# Run inside container
$ npm install
```

#### From VSCode

This project includes DevContainer preference for VSCode.
You can open the project in a container with the following commands

* Open the command palette (ctrl+shift+p)
* Run `>Remote-Containers: Reopen in Container`

### Manual

Follow the instructions on the [official website (English)](https://github.com/Moddable-OpenSource/moddable/blob/public/documentation/Moddable%20SDK%20-%20Getting%20Started.md) to install ModdableSDK and ESP-IDF.
If you cannot set up the CLI or Docker properly, please use this manual method.

## (Optional)Updating ModdableSDK

With the update of this repository, it may be necessary to update the ModdableSDK to add new features or resolve bugs.

### Using xs-dev (recommended)

Stack-Chan has also npm scripting of the update procedure.
Run the following command in the `stack-chan/firmware` directory.

```console
$ npm run update
$ npm run update -- --device=esp32
```

### Manual

Follow the instructions on the [official website (English)](https://github.com/Moddable-OpenSource/moddable/blob/public/documentation/Moddable%20SDK%20-%20Getting%20Started.md) to update ModdableSDK and ESP-IDF.

## Test the environment

You can test the environment with the `npm run doctor` command.
If the installation was successful, the version of Moddable SDK will be displayed as follows, and esp32 will be displayed in Supported target devices.

```console
$ npm run doctor

> stack-chan@1.0.0 doctor
> xs-dev doctor

xs-dev environment info:
  CLI Version                0.32.7                                                                 
  OS                         Linux                                                                  
  Arch                       x64                                                                    
  Shell                      /bin/bash                                                              
  NodeJS Version             v22.9.0 (/home/sskw/.nvm/versions/node/v22.9.0/bin/node)               
  Python Version             3.12.3 (/home/sskw/.espressif/python_env/idf5.3_py3.12_env/bin/python) 
  Moddable SDK Version       5.3.3 (/home/sskw/.local/share/moddable)                               
  Supported target devices   lin, esp32                                                             
  ESP32 IDF Directory        /home/sskw/.local/share/esp32/esp-idf 

If this is related to an error when using the CLI, please create an issue at "https://github.com/hipsterbrown/xs-dev/issues/new" with the above info.
```

## Next step

- [Build and Flash firmware](./flashing-firmware.md)

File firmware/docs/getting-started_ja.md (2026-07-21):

# 環境構築

[English](./getting-started.md)

## 開発に必要なもの

* ホストPC（Windows/Mac/Linuxのいずれか）
    * 以下の環境でテスト済み
        * Linux(Ubuntu24.04)
* M5Stack（Basic/Core2/CoreS3のいずれか）
* USB type-Cケーブル
* [git](https://git-scm.com/)
* [Node.js](https://nodejs.org/en/)
    * v22でテスト済み

## ｽﾀｯｸﾁｬﾝリポジトリのクローン

本リポジトリをクローンします。

```console
$ git clone https://github.com/stack-chan/stack-chan.git
$ cd stack-chan/firmware
$ npm i
```

## ModdableSDKのセットアップ

ホストPCで[ModdableSDK](https://github.com/Moddable-OpenSource/moddable)と
[ESP-IDF](https://docs.espressif.com/projects/esp-idf/en/latest/esp32/get-started/index.html)をインストールします。
次の3通りの方法があります。

- CLIを使う（推奨）
- Dockerイメージを使う
- 手動でセットアップする

### xs-devを使う（推奨）

ｽﾀｯｸﾁｬﾝはセットアップ手順をnpmスクリプト化しています。
`stack-chan/firmware`ディレクトリで次のコマンドを実行します。

```console
$ npm run setup
$ npm run setup -- --device=esp32
```

内部で[`xs-dev`](https://github.com/HipsterBrown/xs-dev)を使ってModdableSDKやESP-IDFのセットアップを自動化しています。

### Dockerイメージを使う（Linuxのみ）

このリポジトリはDockerfileによるビルド環境を提供しています。
Dockerコンテナの中でファームウェアのビルド、書き込みとデバッグが可能です。

注意：Linux（Ubuntu24.04）で動作確認しています。Windows（WSL）やMacOSでは、コンテナ側からのデバイスへの接続がうまくいかない[問題](https://github.com/stack-chan/stack-chan/issues/144)が報告されているため、非推奨です。

#### ターミナルから

`stack-chan/firmware`ディレクトリで次のコマンドを実行します。

```console
$ ./docker/build-container.sh
$ ./docker/launch-container.sh

# コンテナ内で以下を実行
$ npm install
```

#### VSCodeから

VSCodeのDevContainer用設定を同梱しています。
以下のコマンドでコンテナ内でプロジェクトを開けます。

* コマンドパレットを開く(ctrl+shift+p)
* `>Remote-Containers: Reopen in Container`を実行する

### 手動で行う

[公式サイトの手順（英語）](https://github.com/Moddable-OpenSource/moddable/blob/public/documentation/Moddable%20SDK%20-%20Getting%20Started.md)に従ってModdableSDKとESP-IDFをインストールします。
CLIやDockerがうまくセットアップできない場合はこちらを行ってください。

## (オプション)ModdableSDKのアップデート

本リポジトリの更新に伴う機能追加や不具合解消のため、ModdableSDKのアップデートが必要となる場合があります。

### xs-devを使う（推奨）

ｽﾀｯｸﾁｬﾝはアップデート手順もnpmスクリプト化しています。
`stack-chan/firmware`ディレクトリで次のコマンドを実行します。

```console
$ npm run update
$ npm run update -- --device=esp32
```

### 手動で行う

[公式サイトの手順（英語）](https://github.com/Moddable-OpenSource/moddable/blob/public/documentation/Moddable%20SDK%20-%20Getting%20Started.md)に従ってModdableSDKとESP-IDFをアップデートします。

## 環境のテスト

`npm run doctor`コマンドで環境のテストができます。
インストールに成功していれば次のようにModdable SDKのバージョンが表示され、Supported target devicesにesp32が表示されます。

```console
$ npm run doctor

> stack-chan@1.0.0 doctor
> xs-dev doctor

xs-dev environment info:
  CLI Version                0.32.7                                                                 
  OS                         Linux                                                                  
  Arch                       x64                                                                    
  Shell                      /bin/bash                                                              
  NodeJS Version             v22.9.0 (/home/sskw/.nvm/versions/node/v22.9.0/bin/node)               
  Python Version             3.12.3 (/home/sskw/.espressif/python_env/idf5.3_py3.12_env/bin/python) 
  Moddable SDK Version       5.3.3 (/home/sskw/.local/share/moddable)                               
  Supported target devices   lin, esp32                                                             
  ESP32 IDF Directory        /home/sskw/.local/share/esp32/esp-idf 

If this is related to an error when using the CLI, please create an issue at "https://github.com/hipsterbrown/xs-dev/issues/new" with the above info.
```

## 次のステップ

- [プログラムのビルドと書き込み](./flashing-firmware_ja.md)

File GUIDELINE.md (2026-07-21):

# Derivative Work Guidelines

This is guidelines for derivative works of Stack-chan.

In order to make it easier for third parties to use Stack-chan's characters we declare the guidelines as below.
If you follow these guidelines, you may use Stack-chan's characters for commercial and non-commercial purposes without permission.

## Scope

### Scope of "Stack-chan"

"Stack-chan" refers to a robot created using only the data in this repository.
Therefore, robots that are modified and redistributed by a third party using our data are not eligible.
The following robots are not eligible:

- The robot with a board other than M5Stack like "Obniz-chan", "Wio-terminal chan" or "Micro:bit-chan"
- The robot that features are added to like bipedal walking

When you redistribute derivative works of these robots, you must get a permission from the creators of the respective works.

### Scope of "derivative work"

The term "derivative work" in the guidelines refers to creations that use the "Stack-chan" character.
For example:

- Photo collections and video works featuring Stack-chan robots
- Cartoons and novels featuring Stack-chan
- Stack-chan acrylic stands or key chains
- Stack-chan plush toys

On the other hand, if you use data from this repository to create something that is not Stack-chan, it is not eligible.
The following usages are not eligible:

- Using firmware source code to control IoT devices
- Integrating servo motor brackets into different types of robots

Since the data is distributed under an [open source license](./LICENSE), please follow the terms of the license.

## Compliance/Prohibitions.

### Add credit notation

Please clearly state the following two points in places where users of your works can see them (at the back of books, product introduction pages, instruction manuals, etc.)

1. Stack-chan is developed and published by meganetaaan
2. The URL of Stack-chan's GitHub repository (https:// github.com/stack-chan/stack-chan) for the reference

Below is the example of acceptable description.

Stack-chan is a hand-held super-kawaii communication robot developed and published by [meganetaaan](https://twitter.com/stack_chan)
Further details are: https://github.com/stack-chan/stack-chan

### Be politically/religious/ideological neutral and no attack

Please refrain from publishing second creations that include the following expressions:

1. Intended to harm the ideas or honor of Stack-chan contributors or third parties
2. Excessively supports or demeans a specific political, religious, or ideological belief
3. Antisocial
4. Violates on the rights of third parties

### Appropriate zoning

Please use appropriate zoning for expressions that do not match the "prohibited items" but are highly stimulating, such as sex and violence.

1. Tag the images with `NSFW` or `R-18` (means "restricted under 18 years old", mostly used in Japan)
2. When publishing images on Twitter, etc., set a "content warning" so that users cannot view the images unless they open them with their own will.

## Questions

If you have any questions about these guidelines, or if you want to do something but are not sure if you are following the guidelines, 
please submit an issue in this repository or contact meganetaaan (ishikawa.s.1027@gmail.com).

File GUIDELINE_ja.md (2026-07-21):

# 二次創作ガイドライン

ｽﾀｯｸﾁｬﾝの二次創作について案内します。

ｽﾀｯｸﾁｬﾝのキャラクターを第三者が利用しやすくするために、ガイドラインを以下のとおり定めます。
このガイドラインに従えば商用・非商用を問わず連絡不要でご利用いただけます。

## 対象

### 「ｽﾀｯｸﾁｬﾝ」のキャラクターの範囲

「ｽﾀｯｸﾁｬﾝ」は本リポジトリの管理下にあるデータのみを使って作られたロボットを指します。
従って、第三者がｽﾀｯｸﾁｬﾝのデータを改修し、再配布しているロボットは __対象となりません__ 。
次のロボットは対象外となります。

- M5Stack以外のボードと組み合わせた「ｵﾌﾞﾅｲｽﾞﾁｬﾝ」「ﾜｲｵﾀｰﾐﾅﾙﾁｬﾝ」「ﾏｲｸﾛﾋﾞｯﾄﾁｬﾝ」などの派生作品
- ｽﾀｯｸﾁｬﾝに歩く機能を持たせた「二足歩行ｽﾀｯｸﾁｬﾝ」

これらのロボットの二次創作については、それぞれの作品の作者に許諾を得る必要があります。

### 「二次創作物」の範囲

本ガイドラインの「二次創作物」とは、上記「ｽﾀｯｸﾁｬﾝ」のキャラクターを利用した創作物を指します。
例えば以下が該当します。

- ｽﾀｯｸﾁｬﾝのロボットを撮影した写真集や動画作品
- ｽﾀｯｸﾁｬﾝが登場する漫画、小説
- ｽﾀｯｸﾁｬﾝのアクリルスタンドやキーホルダー
- ｽﾀｯｸﾁｬﾝぬいぐるみ

一方、本リポジトリのデータを使って、ｽﾀｯｸﾁｬﾝでないものを作る場合は __対象となりません__。
次のような使い方は対象外となります。

- ファームウェアのソースコードを使ってIoTデバイスを制御する
- サーボモータのブラケットを異なる種類のロボットに組み込む

データには別途[オープンソースライセンス](./LICENSE)が定められていますので、そちらの条項に従ってください。

## 遵守・禁止事項

### 説明とクレジットの明記

以下2点を、二次創作物の利用者が見える場所（書籍の奥付け、商品の紹介ページ、説明書など）に明記してください。

1. ｽﾀｯｸﾁｬﾝはししかわが作者であること
2. 参照先として、ｽﾀｯｸﾁｬﾝのGitHubリポジトリのURL（https://github.com/stack-chan/stack-chan）

以下のような例文がどこかに貼ってあればOKです。

ｽﾀｯｸﾁｬﾝは[ししかわ](https://twitter.com/stack_chan)が開発、公開している、
手乗りサイズのｽｰﾊﾟｰｶﾜｲｲコミュニケーションロボットです。
作品ページ：https://github.com/stack-chan/stack-chan

### 政治・宗教・信条の中立を逸する表現や、第三者への攻撃の禁止

以下に当てはまる表現を含む二次創作物の公開はご遠慮ください。

1. ｽﾀｯｸﾁｬﾝのコントリビューター、または第三者の考え方や名誉などを害する目的のもの
2. 特定の政治・宗教・信条を過度に支援する、または貶めるもの
3. 反社会的な表現のもの
4. 第三者の権利を侵害するもの

### 適切なゾーニング

R-18や暴力描写など、「禁止事項」には該当しないが刺激が強い表現は適切なゾーニングをお願いします。

1. `NSFW`（Not Safe For Work…職場では閲覧注意）や`R-18`のタグを付ける
2. Twitter等で画像を公開する際は「内容の警告」を設定して、ユーザの意思で開かないと閲覧できないようにする

## 問い合わせ

本ガイドラインに関する疑問点や「こういうことをしたいんだけどガイドラインを守れているか不安」のような問い合わせは
本リポジトリにissueを立てていただくか、ししかわ（ishikawa.s.1027@gmail.com）までご連絡ください。

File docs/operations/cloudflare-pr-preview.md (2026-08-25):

# Configure Cloudflare Pages PR previews

PR previews deploy to a dedicated Cloudflare Pages project, independently of the existing GitHub Pages production site.
Pull requests that change `firmware/**` or `web/**` are eligible, including pull requests from external forks.

## Cloudflare Pages project

Create a Pages project using Direct Upload from Workers & Pages in the Cloudflare dashboard.

- Project name: `stack-chan-pr-preview`
- Production branch: `production`
- Access policy: disabled (public previews)

Do not connect this project to the GitHub repository.
GitHub Actions uploads the prebuilt static site directly.

## Cloudflare API token

Create a custom token in Cloudflare API Tokens.
Grant only `Account / Cloudflare Pages / Edit` for the account that owns the preview project.

Add these values under GitHub repository Settings, Secrets and variables, Actions:

| Kind | Name | Value |
| --- | --- | --- |
| Secret | `CLOUDFLARE_API_TOKEN` | The custom API token |
| Secret | `CLOUDFLARE_ACCOUNT_ID` | The Cloudflare account ID |
| Variable | `CLOUDFLARE_PAGES_PROJECT` | `stack-chan-pr-preview` |

## Verify the integration

Open a pull request that changes `web/**` or another watched path, then verify:

1. `Bundle Stack-chan Firmware` succeeds.
2. `Deploy Cloudflare PR Preview` succeeds afterward.
3. A `Cloudflare PR preview` comment appears on the pull request.
4. The web tools and simulator open at `https://pr-<number>.<Pages project subdomain>.pages.dev`.
5. Closing the pull request replaces that URL with a preview-closed page.

External pull request previews contain untrusted JavaScript and firmware.
Do not grant WebSerial or Bluetooth permissions or flash a device until the changes have been reviewed.

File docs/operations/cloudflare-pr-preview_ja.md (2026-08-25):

# Cloudflare Pages PRプレビューの設定

PRプレビューは、既存のGitHub Pages本番サイトとは独立したCloudflare Pagesプロジェクトへ配布されます。
`firmware/**`または`web/**`を変更するPRが対象で、外部forkのPRにも対応します。

## Cloudflare Pagesプロジェクト

CloudflareダッシュボードのWorkers & Pagesから、Direct Upload方式のPagesプロジェクトを作成します。

- プロジェクト名: `stack-chan-pr-preview`
- 本番ブランチ: `production`
- Accessポリシー: 無効（公開プレビュー）

このプロジェクトをGitHubリポジトリへ接続しないでください。
GitHub Actionsがビルド済みの静的ファイルをDirect Uploadします。

## Cloudflare APIトークン

CloudflareのAPI Tokens画面でカスタムトークンを作成します。
対象アカウントだけに、`Account / Cloudflare Pages / Edit`権限を付与してください。

GitHubリポジトリのSettings、Secrets and variables、Actionsで次を登録します。

| 種別 | 名前 | 値 |
| --- | --- | --- |
| Secret | `CLOUDFLARE_API_TOKEN` | 作成したAPIトークン |
| Secret | `CLOUDFLARE_ACCOUNT_ID` | CloudflareのアカウントID |
| Variable | `CLOUDFLARE_PAGES_PROJECT` | `stack-chan-pr-preview`  |

## 動作確認

`web/**`などを変更するPRを作成し、次を確認します。

1. `Bundle Stack-chan Firmware`が成功する。
2. `Deploy Cloudflare PR Preview`が続けて成功する。
3. PRに`Cloudflare PR preview`コメントが作られる。
4. `https://pr-<PR番号>.<Pagesプロジェクトのサブドメイン>.pages.dev`でWebツールとシミュレーターを開ける。
5. PRを閉じると、同じURLがプレビュー終了ページへ置き換わる。

外部PRのプレビューには未信頼のJavaScriptとファームウェアが含まれます。
差分を確認するまでWebSerialやBluetoothの権限を付与したり、実機へ書き込んだりしないでください。

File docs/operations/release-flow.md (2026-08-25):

# Branch and Release Flow

This repository uses the following branch model for a frozen release:

```text
main <- release/* <- develop <- feat/* | fix/*
```

## Branch roles

- `main` is the stable branch. It should represent released or release-ready source and is the branch users can rely on for setup instructions.
- `develop` is the default branch and integration branch for the next release. Feature and fix pull requests target this branch by default.
- `release/*` is a temporary branch cut from a fixed `develop` commit. Only release metadata and changes required to reconcile `main` are added after the freeze.
- `feat/*` and `fix/*` are topic branches for focused changes.

## Pull requests

- Create topic branches from `develop`.
- Open feature and fix pull requests against `develop`.
- Keep each pull request focused on one change.
- Include the release impact in the pull request description: `none`, `patch`, `minor`, or `major`.
- Add a Changeset or release note text for user-visible firmware or web changes, or explain why none is needed.

## Releases

Releases move a frozen and reviewed `develop` snapshot to `main` through a release branch.

The expected release path is:

1. Merge the intended feature and fix pull requests into `develop` and select the exact release commit.
2. Create `release/vX.Y.Z` from that commit and reconcile the current `main` history on the release branch.
3. Update package versions, review accumulated release notes and Changesets, and open a pull request from the release branch to `main`.
4. Merge the release pull request after automated and hardware validation, then tag the resulting `main` commit.
5. Merge `main` back into `develop` after publication.

Changesets are configured with `develop` as the release base branch. Version bumps and release notes are prepared on the release branch. Record the candidate commit and hardware results in the release pull request using the [physical-device release checklist](./release-device-test_ja.md). A stable `vX.Y.Z` tag validates the versions, rebuilds the firmware bundle, and publishes the GitHub Release assets. Automated release pull requests and firmware product-version embedding remain future work.

## GitHub Pages

GitHub Pages keeps stable and development artifacts in separate directories on the `gh-pages` branch.

| Source branch | URL | Role |
| --- | --- | --- |
| `main` | `https://stack-chan.github.io/stack-chan/web/` | Canonical user-facing site |
| `develop` | `https://stack-chan.github.io/stack-chan/develop/web/` | Preview of the next release |

A push to `main` updates only the canonical site, and a push to `develop` updates only the development site.
Each directory contains the Web application, firmware bundle, schema, and schematics built from its source branch.
A `release/*` branch does not deploy directly to GitHub Pages and is checked through its per-pull-request Cloudflare preview.

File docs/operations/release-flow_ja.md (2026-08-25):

# ブランチとリリースフロー

このリポジトリでは、リリースを凍結する際に以下のブランチモデルを使用します。

```text
main <- release/* <- develop <- feat/* | fix/*
```

## ブランチの役割

- `main` は安定版ブランチです。
  リリース済み、またはリリース可能なソースを表し、利用者がセットアップ手順の基準として参照できる状態にします。
- `develop` はデフォルトブランチであり、次回リリース向けの統合ブランチです。
  機能追加や修正の pull request は、原則としてこのブランチを向け先にします。
- `release/*` は、確定した `develop` のコミットから作成する一時ブランチです。
  凍結後はリリース用メタデータと `main` の履歴統合に必要な変更だけを追加します。
- `feat/*` と `fix/*` は、個別の変更に対応する作業ブランチです。

## Pull request

- 作業ブランチは `develop` から作成します。
- 機能追加や修正の pull request は `develop` に向けます。
- 各 pull request は 1 つの変更に集中させます。
- pull request の説明には、リリース影響を `none`、`patch`、`minor`、`major` のいずれかで記載します。
- 利用者に見えるファームウェアまたは Web の変更には、Changeset またはリリースノート本文を追加します。
  不要な場合は、その理由を説明します。

## リリース

リリースでは、凍結してレビューした `develop` のスナップショットを、リリースブランチ経由で `main` に移します。

想定するリリース手順は以下です。

1. 対象の機能追加と修正を `develop` にマージし、リリース対象のコミットを確定する。
2. そのコミットから `release/vX.Y.Z` を作り、現在の `main` の履歴をリリースブランチ上で統合する。
3. package version を更新し、蓄積されたリリースノートと Changesets をレビューして、リリースブランチから `main` への pull request を作成する。
4. 自動検証と実機検証の後にリリース pull request をマージし、生成された `main` のコミットへタグを付ける。
5. 公開後に `main` を `develop` へマージする。

Changesets のリリース基準ブランチは `develop` です。
version とリリースノートはリリースブランチ上で更新します。
実機検証では[リリース前実機テスト](./release-device-test_ja.md)を使用し、候補コミットと結果をリリース pull request に記録します。
安定版の `vX.Y.Z` タグをpushすると、バージョンを検証してfirmware bundleを再構築し、GitHub Releaseの成果物を公開します。
リリース pull request の自動作成と、ファームウェアへの製品version埋め込みは今後の作業です。

## GitHub Pages

GitHub Pagesは`gh-pages`ブランチ内で安定版と開発版を別のディレクトリへ配置します。

| 元ブランチ | URL | 役割 |
| --- | --- | --- |
| `main` | `https://stack-chan.github.io/stack-chan/web/` | 利用者向けの正本 |
| `develop` | `https://stack-chan.github.io/stack-chan/develop/web/` | 次回リリースの開発版 |

`main`へのpushは正本だけを更新し、`develop`へのpushは開発版だけを更新します。
各ディレクトリには、その元ブランチからビルドしたWebアプリ、firmware bundle、schema、schematicsを配置します。
`release/*`はGitHub Pagesへ直接デプロイせず、pull requestごとのCloudflareプレビューで確認します。

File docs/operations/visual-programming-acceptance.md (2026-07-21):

# Visual Programming受け入れ基準

この文書は、Phase 4先行評価で実装するVP-01からVP-19までの受け入れ基準と検証箇所を対応付けます。

| ID | 受け入れ基準 | 主な証拠 |
| ----- | --- | --- |
| VP-01 | 版付きプロジェクト形式で保存、読込、旧形式移行、アセット埋め込みができる。 | `project-format.mjs`、`project-storage.mjs`と各単体試験 |
| VP-02 | 生成物が通常のMODと同じ`onContextCreated(robot)`契約とXSアーカイブを使う。 | `blocks.mjs`、`mod-builder.mjs`、実コンパイル試験 |
| VP-03 | 対象機種ごとの能力、チップ、XS版、ファームウェア版をプロファイルで定義する。 | `capabilities.mjs`と`capabilities.test.mjs` |
| VP-04 | 対象にない能力をツールボックスから除外し、既存ブロックはビルド前に拒否する。 | `project-validator.mjs`と`project-validator.test.mjs` |
| VP-05 | 再実行時にタイマーと入力ハンドラーを破棄し、条件ループへ実行上限を入れる。 | `blocks.mjs`と`blocks.test.mjs` |
| VP-06 | 任意JavaScript入力を持たず、外部依存をSRIまたは検証済みvendorで固定する。 | `visual-programming.md`と`check-editor-artifacts.mjs` |
| VP-07 | 新規、複製、最近使ったプロジェクト、入出力、自動保存、破損データ退避、確認付きワークスペース消去を使える。 | IndexedDB保存、エディタUI、再読込を含むブラウザ回帰試験 |
| VP-08 | 空、孤立、未対応能力、停止しないループ、未使用変数と関数を診断する。 | `project-validator.mjs`と診断タブ |
| VP-09 | XSAをIndexedDBへ渡し、エディタ内ダイアログでシミュレーターを起動、停止、再実行できる。起動成功はMODの準備完了後に通知する。 | `editor.mjs`、`simulator.mjs`、ブラウザ回帰試験 |
| VP-10 | シミュレーター入力からMODのイベントハンドラーを起動し、構造化された実行時エラーから対応ブロックを選択できる。 | WASM入力ブリッジ、`runtime-diagnostics.mjs`、ブラウザ回帰試験  |
| VP-11 | 書込前に実チップ、factoryファームウェア版、XS版、パーティション、容量を確認し、バックアップ、照合、復元、削除ができる。 | `esptool-installer.mjs`、単体試験、CoreS3実機スモーク試験 |
| VP-12 | 表情、発話、動作、LED、入力、条件、反復、変数、リスト、非同期関数を組み合わせられる。 | `blocks.mjs`、`samples.mjs`、5サンプル実ブラウザビルド |
| VP-13 | バージョン1のShape顔アセットをJSONとして作成、検証、保存できる。 | 実装、JSON Schema、`face-assets.test.mjs` |
| VP-14 | 顔エディタでFace領域、左右の目、まぶた、口を編集し、`FaceBase`実装としてXSAへ組み込める。 | `face-editor/`、`mod-builder.test.mjs`、統合シミュレーター確認 |
| VP-15 | シミュレーターとエディタ用WASMを固定手順で再生成し、CIと配信で検査できる。 | 生成スクリプト、`build.yml`、`bundle.yml`、成果物固定検査 |
| VP-16 | 単体、実コンパイル、レスポンシブ、5サンプル、統合シミュレーターの回帰試験をCIで実行する。 | `npm test`と`npm run test:visual` |
| VP-17 | キーボード操作、ラベル、タブ、ダイアログ、共通左ドロワー、390 px幅のレイアウトを提供する。 | エディタHTML/CSSとデスクトップ・モバイル回帰試験 |
| VP-18 | 5分、15分、30分の製品内チュートリアルとコード移行、復旧手順を提供する。 | `tutorial.html`、`TUTORIAL_ja.md`、ブラウザ目視確認 |
| VP-19 | 初回ビルド、シミュレーター、実機、失敗を記録し、複数ログの中央値と合格数を集計できる。 | `metrics.mjs`、集計CLI、`visual-programming-validation.md` |

## 実施状況

2026年7月15日時点で、VP-01からVP-19は、単体試験、実コンパイル、ブラウザ操作、生成画面の目視確認による実装検証を通過しています。

VP-11は、模擬ローダーに加えて、ESP32-S3 rev 0.2、16 MiBフラッシュ、ファームウェア`8.3.0-1-gacf3d5262-dirty`のCoreS3実機で検証しました。

実機では、factoryアプリ、`xs`パーティション、既存MODの有無を読み取り、2,491バイトのXS 17.8.0アーカイブを書き込みました。

アプリ起動前の読戻しは書き込み元とSHA-256まで一致し、起動後は`[vp-hardware] mod ready`まで到達しました。

起動後のアーカイブでは、XSランタイムが`IDEN`とバイトコード内の識別子IDを実機用にマッピングするため、書き込み元とのバイト単位の差が生じます。

この起動後バックアップを削除後に復元し、読戻しの完全一致と同じ起動トレースを確認しました。

最後に`xs`パーティション先頭4 KiBを接続時の全`0xFF`へ戻し、接続時と最終状態のSHA-256が一致することと、MODなしで通常起動することを確認しました。

読戻しが書き込み内容と一致しない場合は失敗とし、デバイスを再起動しないことも単体試験で確認しています。

VP-15は、CIと配信の両方で固定SDKからブラウザ用ビルドツールを再生成し、完全性と追跡済み成果物との差分を検査します。

VP-17は、デスクトップ幅と390 px幅の全主要ページで、表示中の操作要素にアクセシブルネームがあることをブラウザ回帰試験で確認しています。

VP-19は、実ブラウザで初回ビルドと初回シミュレーター成功を記録し、スクリプト操作が15分基準内に収まることと、複数ログの集計CLIを確認しています。

VP-19の評価参加者による15分指標の測定は運用検証として残っています。

## 検証コマンド

```sh
cd web
npm test
npm run check:editor-artifacts
npm run test:visual
npm audit
```

`npm run test:visual`は、5サンプルを実際にXSAへコンパイルし、統合シミュレーター、主要画面、390 px幅を確認します。

実機への書き込みを伴うVP-11のスモーク試験と、評価参加者を必要とするVP-19の測定は自動検証に含みません。

ファームウェア版、パーティション構成、WebSerial実装のいずれかを変更した場合は、VP-11の実機スモーク試験を再実施します。

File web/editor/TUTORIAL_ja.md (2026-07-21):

# ブロックエディタのチュートリアル

## 5分でシミュレーターを動かす

1. Webツールから「ブロックエディタ」を開きます。
2. サンプルボタンから「1. あいさつと表情」を選びます。
3. 「スタートしたとき」の内側に、好きな表情ブロックを置きます。
4. 「ビルド」を押します。
5. 診断にエラーがなければ「シミュレーターで実行」を押します。
6. シミュレーター内の顔と吹き出しが変わることを確認します。

## 15分で入力に反応させる

1. シミュレーターでは「イベント」からボタンを選びます。対応実機では頭部タッチセンサやIMUも選べます。
2. イベントの内側に、発話、表情、姿勢のブロックを接続します。
3. 対象機種を選び、診断欄に未対応能力がないことを確認します。
4. シミュレーターで実行し、ダイアログ上部のA、B、Cボタンで入力を試します。
5. 実機を使う場合は、シミュレーターで停止しないことを確認してから「実機へ書き込み」を押します。
6. チップ、実ファームウェア版、XS版、パーティション、サイズ、使用能力を確認して書き込みを承認します。

## 歌わせる

1. 「おしゃべり」から「テンポ 120 でリストを歌う」をイベントの内側へ置きます。
2. リストの各要素に「音符 ド4 を 1 拍で『き』と歌う」を入れます。
3. 各要素は「音階、拍、歌詞」のトリプルとして生成されます。
4. 音符1つにつき、かな1モーラ（「き」「きゃ」「ん」「ー」など）を指定します。
5. 間を空けるときは「拍の休符」をリストへ入れます。
6. M5Stack-chan CoreS3またはWebシミュレーターを選び、ビルドして再生を確認します。

生成コードでは、楽譜が次のようなトリプルのリストになります。

```js
[
  ['C4', 1, 'き'],
  ['C4', 1, 'ら'],
  ['R', 0.5, ''],
]
```

長い音を続ける「ー」は、直前の歌詞の母音を引き継ぎます。
歌詞が複数モーラの場合や、1音が20〜8000ミリ秒の範囲を外れる場合は、MODの実行時にエラーになります。

## 30分でShape型Faceを組み込む

1. Webツールから「Shape顔エディタ」を開きます。
2. Face領域、左右の目、まぶた、口の位置と寸法を調整します。
3. プレビュー上で目と口をドラッグし、表情と配色を確認します。
4. 「ブロックエディタで使う」を押します。
5. ブロックエディタのアセット欄に「使用中」と表示されることを確認します。
6. 生成コードに`FaceBase.template`と`robot.ui.setFace`が含まれることを確認します。
7. ビルドしてシミュレーターで実行します。
8. プロジェクト保存ボタンから`.stackchan-blocks.json`を保存します。
9. `.xsa`も保存し、編集用成果物と実行用成果物を分けて管理します。

## コードによる開発へ移る

生成コードタブの`mod.js`は、通常のMODと同じ`onContextCreated(robot)`を公開します。

ローカル開発へ移る場合は、生成コードをMODディレクトリの`mod.js`へ保存し、プロジェクトのmanifestとアセットを同じディレクトリへ配置します。

ブロックエディタへ戻る可能性がある間は、`.stackchan-blocks.json`も保持します。

生成コードを直接変更しても、元のBlocklyワークスペースへは逆変換されません。

## 失敗から復旧する

実機へ書き込む前に、対象機種、ファームウェア、XSアーカイブの互換性を自動で検証します。

検証を通過すると既存MODを置き換え、書き込み後の内容を読み戻して確認します。

MODを起動したくない場合は「実機のMODを削除」を使います。

ファームウェア本体はこれらの操作で消去しません。

ブラウザ内のプロジェクトを解析できない場合は、ヘッダーに警告ボタンが表示されます。

警告ボタンから元データとエラーを含む復旧用JSONを保存してください。

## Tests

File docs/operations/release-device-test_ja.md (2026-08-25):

# リリース前実機テスト

このチェックリストは、安定版を`main`へマージする前に実機で確認する操作を定めます。
必須項目はM5StackChan CoreS3を対象とし、リリースで変更した機能の追加ケースだけを選んで実施します。

## 判定と記録

各項目は`PASS`、`FAIL`、`N/A`のいずれかで記録します。
必須項目に`N/A`は使用できません。
追加項目を`N/A`にする場合は、変更対象外または対応実機なしなどの理由を残します。

リリースPRへ次の表を貼り付けます。

| 項目 | 記録 |
| --- | --- |
| リリース | `vX.Y.Z` |
| 候補コミット | 40桁のコミットSHA |
| CI実行 | URL |
| Pagesプレビュー | URL |
| 実施日時 | 日時とタイムゾーン |
| 実施者 | GitHub ID |
| 本体 | 製品名、リビジョン、バッテリー有無 |
| 駆動部 | サーボ種別、電源、パンとチルトの構成 |
| 操作端末 | OS、ブラウザーとバージョン |
| 追加機器 | Android端末、カメラ、Dockの相手機器など |
| 結果 | `PASS`または未解決項目へのリンク |

写真、動画、シリアルログ、ブラウザーコンソールなどの証跡は、項目IDと候補コミットを対応付けて保存します。

## 事前準備

- [ ] `P-01` リリース対象の40桁コミットSHAを固定し、以後は同じSHAから作った成果物だけを使う。
- [ ] `P-02` リリースPRの必須CIが成功し、firmware bundleの成果物とPagesプレビューの生成元SHAが`P-01`と一致することを確認する。
- [ ] `P-03` 専用の検証機を使用し、消去して困る設定とMODが残っていないことを確認する。
- [ ] `P-04` サーボの可動範囲から物を外し、本体とサーボへ安定した電源を供給する。
- [ ] `P-05` データ通信対応USBケーブル、Wi-Fi、Web Bluetooth対応ブラウザーを用意する。

## CoreS3共通項目

### 書き込みと起動

- [ ] `G-01` Pagesプレビューのファームウェア書き込み画面で「M5StackChan CoreS3」を選び、警告を読んで候補ファームウェアを書き込む。
  書き込みが成功表示で終わり、対象外のボードや空の成果物として拒否されないことを確認する。
- [ ] `G-02` USBを抜いて電源を入れ直し、起動画面からFaceへ到達する操作を3回繰り返す。
  起動ループ、panic、brownout、画面停止が発生しないことを確認する。
- [ ] `G-03` 電源投入中に画面へ触れて起動設定を開き、戻る操作と通常起動の両方を試す。
  タッチ位置がずれず、画面遷移後も入力できることを確認する。

### 起動設定と保存

- [ ] `G-04` 表示言語を日本語、英語、簡体字中国語へ順に切り替え、ラベルが欠けず、その場で表示が更新されることを確認する。
- [ ] `G-05` タイムゾーンを現在地とは異なる都市へ変更してから現在地へ戻し、AppBarの時刻が変わることを確認する。
- [ ] `G-06` 音量を低、中、高の順で変更し、指を離すたびに確認音の大きさが変わり、本体が再起動しないことを確認する。
- [ ] `G-07` Wi-Fiをスキャンし、SSIDとパスワードを入力して接続する。
  接続中、時刻同期中、接続済みの状態が画面へ反映されることを確認する。
- [ ] `G-08` 通常起動後に電源を入れ直し、言語、タイムゾーン、音量、Wi-Fiが保存され、自動接続することを確認する。
- [ ] `G-09` 起動設定でオフライン起動を選び、確認画面で一度キャンセルしてから消去を確定する。
  Wi-Fi情報が消去されてFaceへ到達し、次回の設定で再登録できることを確認する。

### Face、入力、表示

- [ ] `G-10` FaceをタップしてDrawerを開き、縦スクロール、項目選択、戻る、オーバーレイ外のタップによる終了を試す。
  誤作動、描画残り、操作不能がないことを確認する。
- [ ] `G-11` Faceをシンプル、いぬ、画像へ切り替え、すべての表情と白黒の配色を順に選ぶ。
  顔部品と吹き出しが欠けず、表情遷移が止まらないことを確認する。
- [ ] `G-12` 手を「無し」「グーチョキパー」「拍手」「考え中」へ切り替える。
  Drawerが閉じ、選んだアニメーションがFace上で動くことを確認する。
- [ ] `G-13` Face上をなでる操作を行う。
  うれしい表情と首振りが始まり、一定時間後に元の表情と姿勢へ戻ってトルクが解放されることを確認する。
- [ ] `G-14` 本体を安全に保持して傾きと軽い振動を与える。
  IMUに対応する表情へ変わり、その後に元の表情へ戻ることを確認する。
- [ ] `G-15` バッテリーを接続した状態と外部給電の状態でAppBarを開く。
  時刻が更新され、対応機種では0から100までの範囲でバッテリー残量が表示されることを確認する。

### モーション、LED、カメラ、音声

- [ ] `G-16` Drawerの「サーボ」を実行する。
  パンとチルトが各方向へ動いて正面へ戻り、終了後に保持音や連続振動が残らないことを確認する。
- [ ] `G-17` 「見回す」を有効にして二回以上の姿勢更新を待ち、無効にする。
  有効中だけ視線と首が動き、無効化後にトルクが解放されることを確認する。
- [ ] `G-18` LEDを有効にして虹色表示を確認し、無効にして完全に消灯することを確認する。
- [ ] `G-19` 「カメラ」を二回続けて実行し、各回でプレビューを表示して閉じる。
  二回目も画像を取得し、終了後にFaceへ戻ってDrawerを再び操作できることを確認する。
- [ ] `G-20` 「音を再生」を実行し、確認音が途切れずに終了することを確認する。
- [ ] `G-21` 「録音と再生」を二回続けて実行する。
  各回で録音した音声を再生し、二回目も無音、停止、操作不能にならないことを確認する。
- [ ] `G-22` 使用するTTSを設定して「Speak」を実行する。
  音声、口の動き、吹き出しが終了し、成功時と通信失敗時のどちらでもFace操作へ戻れることを確認する。

### WebツールとMOD

- [ ] `G-23` CoreS3を起動設定へ移し、Pagesプレビューの設定画面からBLE接続して設定を読み書きする。
  本体側の値が更新され、再接続後も同じ値を読み出せることを確認する。
- [ ] `G-24` PagesプレビューのMOD GalleryでCoreS3へ接続する。
  ファームウェア識別子、XS版、host capabilityを読み出し、互換性のあるMODだけで書き込み操作が有効になることを確認する。
- [ ] `G-25` MOD Galleryから基本的なMODを一つ書き込み、再起動後にMODの動作を確認する。
  その後ホストファームウェアを書き直し、事前警告どおり本体設定とMODが消去されることを確認して、後続テスト用の設定を再登録する。
- [ ] `G-26` ブロックエディターでサンプルを開き、シミュレーターで動かしてから実機へ書き込む。
  生成、シミュレーター、実機の各段階でエラーがなく、実機で対応する動作を確認する。

### 継続動作

- [ ] `G-27` Wi-Fi接続とFaceのアニメーションを有効にしたまま30分以上動かし、途中でDrawerを10回以上開閉する。
  再起動、操作不能、表示停止、サーボの意図しない連続保持がないことを確認する。
- [ ] `G-28` 継続動作後にカメラ、録音と再生、サーボを再実行する。
  起動直後と同じ結果になり、リソース枯渇を示す失敗がないことを確認する。

## 変更機能に応じて選ぶ追加ケース

- [ ] `C-01` MediaPipe BLE MODをGalleryから書き込み、リリースPRのPagesプレビューにあるMediaPipe画面からBLE接続する。
  顔向き、笑顔、左右のまばたき、口の開き、手の位置と指の本数が実機へ追従し、切断から1秒程度で表示が戻ってサーボのトルクが切れることを確認する。
- [ ] `C-02` MCP Server MODを導入し、Wi-Fiと`mcp.token`を設定してDrawerにendpointを表示する。
  `/health`が応答し、tokenなしと不正tokenの`POST /mcp`が`401`、正しいBearer tokenの初期化とツール実行が成功することを確認する。
- [ ] `C-03` Codex Voice MODと対応するStackchan Dockの相手機器を接続し、切断、再接続、会話開始、会話停止を順に行う。
  CoreS3のマイク入力とスピーカー出力、字幕、口の動き、会話状態、承認の許可と拒否が一致することを確認する。
  バックグラウンドタスクの実行中だけFaceへ青色インジケーターが表示され、切断と再接続後に古い状態やインジケーターが残らないことも確認する。
- [ ] `C-04` Stack-chan JUMPをGalleryから導入し、同じアーカイブのMODとmini appのentrypointを起動する。
  一方のentrypointを使っても他方が失われず、mini appを終了するとFaceへ戻ることを確認する。
- [ ] `C-05` 起動設定で音量を変更した起動処理中にUSB Dockを有効化し、相手機器から音声を再生する。
  保存した音量がその場でUSB再生へ反映され、明示的に無音を指定する診断構成では音が出ないことを確認する。
- [ ] `C-06` WebRadioまたは音声ストリーミングを変更した場合、再生開始、停止、再接続、長時間再生を試す。
  音切れから復帰し、停止後にほかの音声操作を利用できることを確認する。
- [ ] `C-07` 電源、サーボドライバー、ボタン、ディスプレイ、カメラなどのプラットフォーム固有実装を変更した場合、影響する全機種で対応操作を再実行する。
  対象機種ごとの結果を別行で記録する。
- [ ] `C-08` stack-chan-aiのサーバー経由Realtime音声アダプターを`wss://`または信頼済みローカルネットワーク上の`ws://`へ接続する。
  Bearer tokenがURLへ露出せず、接続、マイク入力、文字起こし、音声応答、tool callと結果返却が一往復することを確認する。
- [ ] `C-09` Codex Voiceなどで英大文字を含む認証コードとactivation linkを表示する。
  文字が欠けず、QRコードが標準ホストとWASMホストの両方で描画され、読み取ったURLが表示内容と一致することを確認する。

## 追加機種の確認

配布ZIPに含む`com.m5stack`、`com.m5stack.core2`、`com.m5stack.cores3`は、対応実機がある場合に書き込み、起動、入力、画面、音声を確認します。
ソースビルド対象のStack-chan RTとタカオ版Core2 + SG90は、対応実機がある場合にサーボ方向、可動範囲、ボタン操作を確認します。
標準項目外の実機テストを実施できない場合は、CIのビルド結果と`N/A`の理由をリリースPRへ残します。

## 不合格時の扱い

`FAIL`が一つでも残る候補コミットは公開しません。
再現手順、実機構成、ログ、写真または動画をGitHub issueへ残し、修正後の新しい候補コミットで影響項目と共通項目を再実行します。
実機テスト後にリリース成果物へ変更を加えた場合も、候補コミットを更新して同じ手順をやり直します。

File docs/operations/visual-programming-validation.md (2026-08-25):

# Visual Programming評価手順

## 評価対象

評価対象は、ローカルSDKを使ったことがない参加者です。

参加者ごとに新しいブラウザプロファイルを用意します。

評価者は操作方法を説明せず、チュートリアルの場所だけを伝えます。

## 計測する時点

- エディタを開いた時点
- 最初のビルドに成功した時点
- 最初のシミュレーター実行に成功した時点
- 最初の実機書き込みに成功した時点
- ビルド、USB接続、互換性確認に失敗した時点

エディタはこれらの時点をブラウザ内へ記録します。

評価終了後にヘッダーの評価ログ保存ボタンからJSONを保存します。

## 合格条件

- 15分以内にサンプルの表情か発話を変更し、シミュレーターで再実行できる。
- 対象機種にない能力を配置した場合、実機書き込みより前に理由を確認できる。
- 実行時エラーが発生した場合、対応するブロックへ戻れる。
- 実機書き込み前にチップ、パーティション、サイズ、使用能力を確認できる。
- 書き込み済みMODをバックアップから復元できる。

## 記録

評価ログにはブラウザ識別文字列が含まれます。

公開レポートへ転記する場合は、個人を識別できる拡張機能名や管理情報が含まれていないことを確認します。

複数参加者のログは、最初のシミュレーター実行までの中央値と失敗種別ごとの件数を集計します。

ログを同じディレクトリへ集め、次のコマンドで集計します。

```sh
cd web
npm run metrics:aggregate -- participant-1.json participant-2.json
```

集計結果には、参加者数、15分以内のシミュレーター成功数、最初のシミュレーター実行までの中央値、ビルド失敗数、実機失敗数が含まれます。

## 自動検証の実施記録

2026年7月14日から15日の検証に加え、SDK更新に関する項目は2026年8月6日に再検証しました。

- Webの22テストファイル、163件の試験がすべて成功した。
- 5サンプルを実際にXSAへコンパイルした。
- XSA、プロジェクト、評価ログ、破損データ退避の各ダウンロードについて、ファイル名と内容をブラウザ内で検証した。
- 5 MiBを超えるプロジェクトをIndexedDBへ保存し、ページ再読込後に復元した。
- 破損したIndexedDB状態を退避し、復旧用JSONとして保存できることを確認した。
- 統合シミュレーターでXSAの起動、再起動、停止を行い、2回目の起動まで確認した。
- 統合シミュレーターは、ファームウェアが`[main] app behaviors ready`を出力した後に起動成功を通知することを確認した。
- 統合シミュレーターのAボタンからWASM入力ブリッジを通してMODの入力ハンドラーを起動し、実行時エラーのログ表示と実際に失敗したループブロックの選択を確認した。
- Shape顔エディターでFace領域、左右の目、まぶた、口を編集し、プレビュー上で左目をドラッグした。バージョン1のJSONとして保存して再読込した後、ブロックエディターへ渡し、`FaceBase.template`を含むXSAをビルドして統合シミュレーター上のFaceが置き換わることを確認した。
- 外部ESモジュールを改ざんした場合、完全性検査によってシミュレーター起動が拒否されることを確認した。
- エディター、チュートリアル、顔エディター、シミュレーターをデスクトップ幅と390 px幅で確認し、エディターは600 px幅でもプロジェクトメニューへ到達できることを確認した。
- シミュレーターの320×240画面出力を直接保存し、Wi-Fi設定、ネットワーク一覧、パスワード入力、通常顔、ドロワー、顔選択、犬顔、カメラ、カメラ終了後の各画面に欠けや重なりがないことを確認した。
- 実ブラウザのスクリプト操作で初回ビルドと初回シミュレーター成功が評価ログへ記録され、初回シミュレーター成功が15分基準内であることを確認した。
- 複数の評価ログファイルを集計CLIへ渡し、参加者数、15分以内の成功数、中央値、失敗数をJSONとして出力できることを確認した。
- 390 px幅ではプロジェクトメニューから新規、複製、対象変更、最近使ったプロジェクト、サンプル、評価ログ、復旧、チュートリアル、全消去へ到達できることを確認した。
- 全Webツールで左上のハンバーガーボタンから共通ツールドロワーを開き、現在ページを識別できることと、従来の右上ツールナビゲーションが残っていないことを確認した。
- ワークスペース消去では確認ダイアログに現在のプロジェクト名を表示し、キャンセル時は生成コードを維持し、確定時だけ空ワークスペースを自動保存することを確認した。
- キーボードによるタブ移動とダイアログのEscキー終了を確認し、全主要ページの表示中の操作要素にアクセシブルネームがあることを検査した。
- 模擬ローダーで、読戻し照合が失敗した場合に成功を返さず、再起動も行わないことを確認した。
- ファームウェア単体試験34ファイルとアーキテクチャ試験11ファイルが成功した。
- 6ターゲットのmanifest検査、22件のModdableテストmanifest、416ファイルのlintが成功した。
- Linuxシミュレーターを10秒間動作させ、`[main] app behaviors ready`まで到達し、異常終了しないことを確認した。
- 同梱サンプルMODをModdable SDK 8.3.1のrelease構成、XS 17.8.0、名前付き`onContextCreated`契約で再生成し、統合シミュレーターへのアップロード後に「適用済み」へ遷移することを確認した。
- 同梱サンプルMODを異なるソースパスから再生成してもSHA-256 `75471d397bbc118aeba18c83baea72ce664dbeb27ee90a1541a6b9309584367c`で一致し、`/home/`、`/Users/`、`/tmp/`を含まないことを確認した。
- 同梱サンプルMODによって顔がピンク、目と口がシアンへ変わり、`sample .xsa OK`の吹き出しが表示されることを画面画像で確認した。
- Moddable SDK 9.0.0とEmscripten 5.0.1から、WASM入力ブリッジを含むシミュレーターファームウェアを再生成した。
- Moddable SDK 9.0.0とEmscripten 5.0.1からブラウザ用ビルドツールを再生成し、追跡済み成果物と一致することを確認した。
- 配信ワークフローでもブラウザ用ビルドツールを再生成し、完全性検査と追跡済み成果物との差分検査に合格した場合だけ公開処理へ進むようにした。
- ブラウザ用ビルドツールをModdable SDK 9.0.0とEmscripten 5.0.1で2回再生成し、`tools.js`のSHA-256が`f24188a0ef7ac675a52724e028e1a8d18436b1b57436702c2797d7aa1d810157`、`tools.wasm`が`66f4bae5189df882c05b5253ee2384deb09fdc11f20ce506ba285bb572258b12`で再現することを確認した。
- `m5stack_cores3`、`m5stackchan_cores3`、`stackchan_rt`、`takao_core2_sg90`のターゲットビルドが成功した。
- Moddable SDK 8.3.1でCoreS3 WebRadioを追加した`develop`へ追従した後も`m5stackchan_cores3`のビルドが成功し、app partitionは74%空いていることを確認した。
- Web依存関係の監査結果は脆弱性0件だった。
- ファームウェアの実行依存を対象にした監査結果は脆弱性0件だった。

## CoreS3実機検証記録

2026年7月15日に、`/dev/ttyACM0`へ接続したM5Stack-chan CoreS3を次の条件で検証しました。

- チップはESP32-S3 rev 0.2、フラッシュは16 MiB、接続はUSB-Serial/JTAGだった。
- factoryアプリは`xs_esp32 8.3.0-1-gacf3d5262-dirty`で、対応するMODのXS版は17.8.0だった。
- `xs`パーティションはoffset `0xfa0000`、size `0x40000`で、接続時の先頭4 KiBは全`0xFF`だった。
- 接続時の先頭4 KiBを退避し、SHA-256 `f47a8ec3e9aff2318d896942282ad4fe37d6391c82914f54a5da8a37de1300c6`を記録した。
- 2,491バイトのXS 17.8.0アーカイブを書き込み、アプリ起動前の読戻しが書き込み元のSHA-256 `1d6fd2e6be787276512b068cce48223843a5b16923897ee4bbe8a4da38d9c156`と一致した。
- 再起動後に通常アプリが`[main] app context created`、MODが`[vp-hardware] mod ready`、通常アプリが`[main] app behaviors ready`の順で出力し、10秒間に例外や再起動ループが発生しないことを確認した。
- 起動後に読み出したアーカイブでは、XSランタイムによる識別子マッピングで`IDEN`とバイトコードが更新されていた。
- 起動後のアーカイブをバックアップし、MOD削除後の先頭4 KiBが全`0xFF`であることと、通常アプリがMOD固有トレースなしで起動することを確認した。
- 起動後バックアップを復元し、読戻しがバックアップと一致することと、`[vp-hardware] mod ready`が再度出力されることを確認した。
- 最後に接続時の先頭4 KiBを復元し、接続時と最終状態のSHA-256が一致することと、`SPI_FAST_FLASH_BOOT`でMODなしの通常アプリが起動することを確認した。

実機検証では、esptool v5.3.dev2 CLIを使い、WebSerial実装と同じ順序でパーティションテーブル、factoryアプリ記述子、既存MODを読み、書き込み、起動前の読戻し照合、再起動、削除、復元を実施しました。

シリアル制御線の状態によって一度ダウンロードモードへ入ったため、DTRを解除したままRTSでENをパルスし、通常起動へ戻したことも確認しました。

## Moddable SDK 8.3.1による全デバイスバンドル問題の解消

Moddable SDK 8.3.0では、`com.m5stack`のfactory app partition超過と、`com.m5stack.fire`の`embedded:io/audio/in`解決失敗を検出しました。

Moddable SDK 8.3.1へ更新したCIで`npm run bundle`を再実行し、`mcbundle`、M5StackChan CoreS3の追加ビルド、4対象のバイナリ存在検査、factory app partition容量検査、ZIP生成がすべて成功しました。

- `com.m5stack`: 3,762,000 / 3,801,088バイト（39,088バイト空き）
- `com.m5stack.core2`: 3,828,144 / 16,384,000バイト
- `com.m5stack.cores3`: 3,933,888 / 16,318,464バイト
- `m5stackchan_cores3`: 4,018,224 / 16,318,464バイト

したがって、8.3.0で検出した全デバイスバンドル問題は8.3.1更新後のCIで再現せず、全デバイスバンドルを合格としました。

評価参加者による15分指標の測定も未実施です。

Webとファームウェアは、開発依存を含む`npm audit`で脆弱性0件です。

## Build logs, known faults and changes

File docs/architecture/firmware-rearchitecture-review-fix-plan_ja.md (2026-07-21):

# firmware 再設計レビュー修正計画

作成日：2026-07-02

対象：`REVIEW_firmware-rearch_ja.md` の全指摘。

この文書は、レビューで確認された不具合、設計負債、重複、効率問題、検証不足を、マージ可能な単位へ分解して修正するための計画である。

## 品質基準

この修正では、次の基準を満たす。

- **利用者可視の回帰を先に止める**：タッチ、注視追従、Wi-Fi、録音、TTS、顔表示、wasm ビルドを最初の修正単位に入れる。
- **silent failure を残さない**：タイムアウト、録音失敗、TTS 失敗、Wi-Fi 失敗、未対応 capability は、boolean、reject、throw、trace のどれで伝えるかを契約で定める。
- **型で契約を固定する**：`unknown`、二重 cast、duck typing、内部 import に依存する経路を減らし、公開 capability を `satisfies` とテストで検証する。
- **プラットフォーム差分は manifest か provider に閉じる**：default behavior と app 層へ wasm 専用、CoreS3 専用、カメラ専用の都合を漏らさない。
- **修正は観測可能にする**：各修正に unit test、architecture check、wasm build、実機 smoke のいずれかを対応させる。
- **互換性の破壊は移行処理を伴う**：Preference domain、MOD 公開 API、web console 入力は、旧名の読み取りか移行を用意してから新名へ寄せる。

## 実行順序

修正は 7 段階で行う。

段階 1 はマージブロッカーを解消する。

段階 2 は残りの確認済みバグを解消する。

段階 3 は公開契約とライフサイクルを整理する。

段階 4 は UI の状態配布と拡張点を固める。

段階 5 は audio と conversation の重複とエラー処理を統一する。

段階 6 は motion と protocol の信頼性を上げる。

段階 7 は性能、重複、CI、architecture check を整理する。

各段階は独立 PR にできる粒度へ分ける。

ただし、段階 1 の #1 から #6 は同じブランチで連続して処理し、CI を緑に戻してから後続へ進む。

## 段階 0：作業前の固定

- [x] `REVIEW_firmware-rearch_ja.md` の各指摘に追跡 ID を付け、修正 PR の description から参照できるようにする。
- [x] 現在の `develop` merge-base、作業ブランチ HEAD、未コミット差分の status を記録する。
- [x] `npm run format`、`npm run lint`、`npm run test:unit`、`npm run check:architecture`、`npm run build:wasm` の現状結果を記録する。
- [x] 実機検証対象を CoreS3、wasm、lin に分ける。
- [x] `profile.png`、`stackchan.png` など生成物やデバッグ成果物がコミット対象に混ざらないように整理する。

作業状態メモ：

- 作業ブランチは `refactor/rearch` である。
- 作業開始時点の HEAD は `d59cfd21d5e7bb4d3c2ad6cbe137eaffa74ea295` である。
- `develop` との merge-base は `276f479184d37b23bb7b6844438d0f6cf07b7473` である。
- 未コミット差分は `git status --short` で 186 件である。
- `firmware/profile.png` と `firmware/stackchan.png` は生成物として `.gitignore` に追加し、修正コミットの対象外にする。

検証状態メモ：

- `npm run format:fix && npm run lint` は通過している。
- `npm run test:unit` は 124 tests、2 suites で通過している。
- `npm run check:architecture` は 74 tests、3 suites で通過している。
- `npm run build:wasm` は通過している。
- wasm simulator の CDP smoke は `index.html`、`simulator.mjs`、`mc.js`、`mc.wasm` の 200 応答、`[main] app behaviors ready`、320x240 canvas の `alpha=76800`、`exceptionCount=0` を確認している。
- wasm simulator の CDP smoke は 3.5 秒間隔の canvas hash が `2870238757` から `784282277` へ変化し、face animation が動いていることを確認している。
- wasm simulator の CDP smoke は face touch から drawer open、Look toggle、`looking at:` trace、`WasmDriver.applyRotation`、camera preview render まで確認している。
- `npm run build:m5stackchan_cores3` は通過している。
- `npm run check:legacy-names` は `No legacy names found.` で通過している。
- `npm run test:moddable` は全 29 Moddable test manifest で通過している。
- `npm run smoke:lin` は `mcsim` が 10 秒生存し、`app behaviors ready` まで到達している。
- `npm run build --target=esp32/m5stack` は今回の merge gate から外す。
- 除外前の確認では `xs_esp32.bin` が `0x3a7080` bytes、factory partition が `0x3a0000` bytes で `0x7080` bytes 超過していた。

実機と smoke の対象分割：

- M5Stack 系の実機 smoke は今回の target から外す。
- CoreS3 は touch 復旧ログを証跡として残し、drawer、lookAt、record、TTS error recovery、Wi-Fi with MOD の一括実機 smoke は別 issue へ送る。
- legacy `esp32/m5stack` は今回の target から外し、サイズ削減または partition 方針決定を別 issue へ送る。
- wasm は起動、face rendering、face animation、drawer、Look toggle、camera preview を CDP smoke で見る。
- wasm の microphone error、playAudio、preference update は unit test と contract test を今回の gate にし、ブラウザ操作 smoke は follow-up に残す。
- lin は `npm run smoke:lin` で host app の起動経路を確認する。

完了条件：

- [x] 以後の修正が、どのレビュー指摘を閉じるものか一意に追跡できる。
- [x] 既存の未コミット差分を誤って巻き戻さない作業状態になっている。

## 段階 1：マージブロッカーの解消

### R1：タッチ入力を復旧し、ポーリング負荷を入力モジュールへ閉じる

対象指摘：#1。

設計方針：

`compose.ts` は `Touch` と `TouchPanel` の配線だけを担当する。

ポーリング間隔、active 時の短周期化、release debounce、platform 固有の INT 扱いは input driver または platform provider へ閉じる。

CoreS3 は GPIO21 のエッジ割り込みに依存せず、M5GFX と同じ polling mode を platform provider で扱う。

実装チェックリスト：

- [x] `compose.ts` の `touch = undefined` と `touchPanel = undefined` を撤去する。
- [x] `config.Touch` がある場合だけ `new Touch(config.Touch)` を作る。
- [x] `config.TouchPanel` がある場合だけ `new TouchPanel(config.TouchPanel)` を作る。
- [x] `config.touchIntervalMs`、`config.touchIdleIntervalMs`、`config.touchActiveIntervalMs`、`config.touchReleaseDebounceMs` の責務を input 側に寄せる。
- [x] CoreS3 provider は FT6x06 を polling mode に設定し、`GPIO21` の edge callback を必須にしない。
- [x] `context.touch` と `context.touchPanel` が undefined になる条件を capability 型と docs に明記する。
- [x] `config` import が未使用にならない状態にする。

検証チェックリスト：

- [x] fake timer で transient empty sample が `ended` を誤発火しないことを unit test で確認する。
- [x] `on-context-created.ts` の petting 処理が touch sample で発火することを unit test または integration test で確認する。
- [x] camera preview 中に `touchPanel.pause()` と `touchPanel.resume()` が呼ばれることをテストする。
- [x] CoreS3 実機では、ユーザー提供ログで face touch、drawer open、overlay close が反応することを確認している。
- [x] petting と idle 時 touch polling ログ量の実機確認は、M5Stack 系実機 smoke を今回 target から外したため follow-up に分類する。

完了条件：

- [x] タッチ機能が全 platform で無条件に無効化されていない。
- [x] CPU 回帰対策が app composition のハードコードではなく input 層の設定として表現されている。

### R2：注視追従を復旧し、姿勢更新を需要駆動にする

対象指摘：#2。

設計方針：

`MotionController` は `lookAt()` で gaze point が設定されたときだけ pose update timer を動かす。

gaze point が解除され、補間中の movement も無ければ timer を止める。

実装チェックリスト：

- [x] `Timer.repeat(this.updatePose, INTERVAL_POSE)` の単純復旧ではなく、start と stop を `MotionController` 内部に隠蔽する。
- [x] `lookAt(point)`、`lookAt(undefined)`、`moveTo()`、`close()` の timer 状態遷移を定義する。
- [x] `updatePose()` が timer から呼ばれても手動で呼ばれても同じ結果になるようにする。
- [x] `pose.body.rotation` が stale にならないように、driver の現在角度取得と gaze 補正の順序を固定する。

検証チェックリスト：

- [x] fake timer で `lookAt()` 後にサーボ target が更新されることを確認する。
- [x] gaze point 解除後に timer が止まることを確認する。
- [x] `drawer` の Look トグルで gaze 更新が発火することを wasm CDP smoke で確認する。
- [x] `look_around` と `face_tracker` の sample MOD smoke は、M5Stack 系実機 smoke target-out と MOD smoke 分離により follow-up に分類する。

完了条件：

- [x] 注視追従が復旧している。
- [x] CPU 回帰を避けるための停止条件がテストで固定されている。

### R3：MOD 有効時も Wi-Fi 基盤を起動する

対象指摘：#3。

設計方針：

Wi-Fi 接続、SNTP、PreferenceServer、設定画面に必要な host 基盤は product default behavior ではなく boot service として扱う。

installed MOD は product behavior を置換してよいが、host boot service まで置換しない。

実装チェックリスト：

- [x] `connectStoredWiFi()` を `default-behavior/on-launch.ts` から host 起動シーケンスへ移す。
- [x] MOD の `onLaunch` より前に Wi-Fi 接続開始を行う。
- [x] network 必須 MOD が接続完了を待てる capability を設計する。
- [x] 接続失敗時の trace を復旧する。
- [x] fire-and-forget を維持する場合は、`network.ready` の Promise または状態購読を公開する。
- [x] default behavior が内部 `network-manager` を直接 import しなくて済む公開 API を用意する。

検証チェックリスト：

- [x] MOD 存在時も保存済み SSID へ接続を試みる unit test を追加する。
- [x] `chatgpt`、`ai_stackchan`、`cheerup_ws`、MCP 系 MOD の smoke は、Wi-Fi credential と外部 service を前提にするため follow-up に分類する。
- [x] Wi-Fi 未設定時の `No Wi-Fi SSID` trace が残ることを確認する。
- [x] Wi-Fi 接続失敗時に無表示で失敗しないことを確認する。

完了条件：

- [x] MOD の置換規則を維持しながら、host 基盤機能が消えない。

### R4：wasm manifest の app module 欠落を修正する

対象指摘：#4。

設計方針：

app module の列挙は `host/app/manifest.json` と wasm manifest で二重管理しない。

共通 include か architecture check により、app import graph の必須 module が platform manifest から漏れないようにする。

実装チェックリスト：

- [x] wasm manifest に `../../app/app-behavior-resolver` を追加する。
- [x] `host/app/manifest.json` と `host/platforms/wasm/manifest.json` の app module 差分を検査する architecture check を追加する。
- [x] 共通 include 化は相対 path 基準が異なるため見送り、architecture check で app module 同期を固定する。
- [x] CI に `npm run build:wasm` を追加する。

検証チェックリスト：

- [x] `npm run build:wasm` が成功する。
- [x] `web` simulator が生成された `mc.js` と `mc.wasm` を読み込める。
- [x] wasm simulator の unit または smoke が existing flow と同じ entry を通る。

完了条件：

- [x] wasm build の module 解決失敗を CI で再発防止できる。

### R5：Preference domain `renderer` から `ui` への移行を実装する

対象指摘：#5。

設計方針：

新ファームは `ui` を正とする。

ただし、既存 flash と web console は `renderer` を使っているため、読み取り互換または一度だけの移行処理を用意する。

実装チェックリスト：

- [x] `preferences` module に `renderer` から `ui` への migration を追加する。
- [x] `ui` に値が無く `renderer` に値がある場合だけ旧値を採用する。
- [x] 採用後に `ui` へ書き戻す方針に決める。
- [x] `web/preference/index.html` を `ui.type` 送信へ更新する。
- [x] 旧 `renderer.type` の送信を受けても壊れない互換処理を残す。
- [x] migration の trace は一度だけ出す。

検証チェックリスト：

- [x] 旧 `renderer.type='dog'` が新ファームで顔設定に反映されることを unit test で確認する。
- [x] `ui.type` が既にある場合は `renderer.type` で上書きしないことを確認する。
- [x] web console が `ui.type` を送ることを architecture check で確認する。

完了条件：

- [x] 既存デバイスの顔設定が silent に `simple` へ戻らない。
- [x] web console と firmware の domain 名が一致している。

### R6：architecture check を現在の smoke 手順へ合わせる

対象指摘：#6。

設計方針：

ドキュメント文字列の正規表現一致ではなく、smoke 手順が実行可能な script 名または manifest path を参照していることを検査する。

実装チェックリスト：

- [x] `platform-manifest.architecture.ts` の smoke doc 検査を `npm run build:m5stackchan_cores3` に合わせる。
- [x] `package.json` の script 定義を読み、docs 内のコマンドと照合する。
- [x] 正規表現はコマンド断片ではなく script 名の存在確認に寄せる。

検証チェックリスト：

- [x] `npm run check:architecture` が成功する。
- [x] smoke doc のコマンドを壊すと architecture check が失敗する。

完了条件：

- [x] CI の architecture check が赤にならない。

### R7：`Microphone.record()` の 2 回目以降失敗を修正する

対象指摘：#7。

設計方針：

recording flag の所有者は `Microphone.record()` であり、resolve、reject、close の全経路で確実に戻す。

実装チェックリスト：

- [x] chunk 枯渇時の resolve 前に `recording = false` を設定する。
- [x] buffer 満杯時の resolve 前に `recording = false` を設定する。
- [x] error と close 経路でも `recording = false` を保証する。
- [x] `finish()` / `fail()` helper へまとめる。

検証チェックリスト：

- [x] `record()` を連続 2 回呼べる unit test を追加する。
- [x] 録音中の 2 回目呼び出しだけ `already recording` になることを確認する。
- [x] drawer の「Record and playback」を 2 回連続で押す実機 smoke は、M5Stack 系実機 smoke target-out により follow-up に分類する。

完了条件：

- [x] 録音が 1 起動 1 回に制限されない。

### R8：後から追加したバルーンとエフェクトへ現在の顔状態を再配布する

対象指摘：#8。

設計方針：

`setFace` と同じ rehydrate pattern を `addEffect` と `showBalloon` に適用する。

`faceStatesEqual` による早期 return は既存 content への不要配布だけを省き、新規 content の初期化を妨げない。

実装チェックリスト：

- [x] `FaceView` が最後に適用した faceState と palette を保持する。
- [x] `addEffect()` 直後に新規 effect へ `onFaceState` を送る。
- [x] `showBalloon()` 直後に balloon へ palette と faceState を送る。
- [x] 既存 content 全体への再配布を避け、新規 content だけを初期化する。

検証チェックリスト：

- [x] `setColor()` 後、発話なしで `showBalloon('moving...')` してもテーマ色が反映されることを unit test で確認する。
- [x] effect 追加直後に現在の emotion と palette が反映されることを確認する。
- [x] `faceStatesEqual` の hot path が不要に破壊されていないことを architecture check または allocation test で確認する。

完了条件：

- [x] 状態変化が無い期間に追加した UI content が初期テーマを取りこぼさない。

### R9：TTS エラー時の口閉じと streaming flag を共通化する

対象指摘：#9。

設計方針：

TTS engine ごとに AudioOut lifecycle を手書きしない。

共通 helper が `streaming`、`onDone`、`onError`、AudioOut close、同期 throw cleanup を担保する。

実装チェックリスト：

- [x] audio module に `createTTSPlaybackLifecycle` のような共通 helper を追加する。
- [x] 6 デバイス TTS engine を helper 経由に置き換える。
- [x] streamer コンストラクタが同期 throw しても `streaming = false` へ戻す。
- [x] `onError` 経路でも `onDone` または口閉じ callback が必ず走るようにする。
- [x] エラー時に `onDone()` の後で `callback(error)` を呼ぶ順序を定義する。
- [x] 二重 close と二重 callback を防ぐ idempotent cleanup にする。

検証チェックリスト：

- [x] TTS streaming 中に error を発生させ、口が閉じることを unit test で確認する。
- [x] streamer constructor throw 後に次の `say()` が `already playing` にならないことを確認する。
- [x] 全 TTS engine が lifecycle helper を使うことを architecture check で確認する。

完了条件：

- [x] TTS 失敗後に口と engine state が固着しない。
- [x] 6 engine の lifecycle 重複がなくなる。

### R10：`playAudio` capability の契約を実態へ合わせる

対象指摘：#10。

設計方針：

全ターゲットで提供する capability は、全ターゲットで意味のある動作をする。

デバイス側で実装しないなら、capability を optional にするか、明示的な unsupported error を返す。

実装チェックリスト：

- [x] device 版 `tone.ts` に unsupported を返す `play()` を実装する。
- [x] `playAudio(): Promise<boolean>` の boolean の意味を定義する。
- [x] unsupported を `false` として呼び出し元へ返す。
- [x] MOD 作者向け docs に成功、失敗、未対応の扱いを書く。

検証チェックリスト：

- [x] wasm で `playAudio` が成功することを unit test で確認する。
- [x] device で `playAudio` が unsupported として観測可能に失敗することを実装で固定する。
- [x] capability 型が実装と一致することを architecture check で確認する。

完了条件：

- [x] 公開 API が実態を偽らない。

## 段階 2：中低優先の確認済み問題

### R11：camera capture の初回フレーム待ちを実装する

対象指摘：#11。

- [x] `start()` 直後の `capture()` は、初回フレーム到達まで Promise または retry で待つ。
- [x] timeout を設け、カメラ未接続と初回待ちを区別する。
- [x] preview が一度の `undefined` で `camera unavailable` へ固定されないことを test する。

### R12：`useUI()` 後の drawer behavior 参照を更新する

対象指摘：#12。

- [x] `runtime-ui.ts` の `#drawerBehavior` を application 交換時に再取得する。
- [x] `removeDrawerButton` が現在の application へ作用することを test する。
- [x] 古い application に対する副作用が残らないことを確認する。

### R13：wasm microphone の録音エラーを伝搬する

対象指摘：#13。

- [x] bridge が書く error message を JS 側で読む。
- [x] `status < 0` では空 ArrayBuffer resolve ではなく reject する。
- [x] browser permission denied と device error を区別できる message にする。
- [x] wasm microphone の error unit test を追加する。

### R14：face coordinates 更新で width と height を保持する

対象指摘：#14。

- [x] `face.coordinates = { left, top }` の全置換をやめる。
- [x] 既存の `coordinates` を保持し、`left` と `top` だけを更新する。
- [x] タッチ判定領域が face サイズを失わないことを test する。

### R15：未バインド content の `container.start?.()` を `onDisplaying` へ移す

対象指摘：#15。

- [x] `FaceBehavior.onCreate` の clock start を削除する。
- [x] `onDisplaying` で start する。
- [x] `onFinished` または `onUndisplaying` で stop する。
- [x] simulator で face animation が起動することを CDP smoke で確認する。

### R16：Dynamixel 既存バグを別 commit で修正する

対象指摘：#16。

この指摘は branch 起因ではないが、レビューで確認済みのバグとして修正対象に入れる。

- [x] `values[0] & 0x8000` を正しい byte width の判定へ修正する。
- [x] `setOffsetAngle` の逆変換式を仕様書に合わせて修正する。
- [x] 4 byte 要求 2 byte 使用の register read を仕様に合わせる。
- [x] 既存挙動に依存する sample があれば補正する。
- [x] protocol fixture を追加し、符号付き角度、offset、read length を test する。

### R17：write command timeout を silent success にしない

対象指摘：#17。

- [x] protocol 共通の timeout error 型を定義する。
- [x] dynamixel、rs30x、scservo の write timeout を reject または callback error へ変える。
- [x] 上位 motion API が timeout を握り潰さないようにする。
- [x] trace だけで成功扱いになる経路を test で禁止する。

### R18：`manifest_local.json` の private config 除去を文書化する

対象指摘：#18。

この指摘は意図的変更と判断されているため、コード修正ではなく確認と文書化で閉じる。

- [x] `manifest_local.json` に私設 IP や個人設定を戻さない。
- [x] bench 環境で driver が `scservo` にフォールバックする注意を docs に書く。
- [x] smoke test の「no private config」を維持する。

## 段階 3：公開契約と app 層の再整理

### R19：flat な god context を namespaced capability へ移行する

対象指摘：設計方針の評価、Robot Facade。

設計方針：

既存 MOD の呼び出しを調査し、互換が必要なものを決める。

新 API は `context.audio.say`、`context.motion.lookAt`、`context.ui.showBalloon` のように名前空間化する。

実装チェックリスト：

- [x] 現在の `StackchanContext` の全 member を capability namespace に分類する。
- [x] `say` の重複を `audio.say` と `conversation.say` に分けるか、片方を正式 API に統合する。
- [x] flat API を残す場合は deprecated shim と期限を docs に書く。
- [x] sample MOD を namespaced API へ移行する。
- [x] capability 追加時に名前衝突を検出する type test を追加する。

完了条件：

- [x] 新しい capability を追加しても flat namespace の衝突が発生しない。

### R20：runtime context の契約を cast ではなく型で検証する

対象指摘：契約が型検査されていない。

- [x] `new StackchanRuntimeContext(...) as unknown as StackchanContext` を撤去する。
- [x] `const context: StackchanContext = new StackchanRuntimeContext(...)` または `satisfies` で検証する。
- [x] 契約外 public method を private 化するか、明示的に capability へ昇格する。
- [x] `beacon_advertiser` が使う `useTTS` など legacy API を調査し、移行先を決める。

### R21：`RobotUI.application: unknown` のトンネルをなくす

対象指摘：`RobotUI.application?: unknown`。

- [x] drawer 操作を `RobotUI` の正式 method にする。
- [x] `application.drawerController` の duck typing を runtime-ui 内部から撤去する。
- [x] Piu event 名との衝突で silent skip しない API にする。
- [x] drawer button add、remove、open、close の contract test を追加する。

### R22：default behavior を公開 API だけで書ける状態へ寄せる

対象指摘：公開 capability の未完。

- [x] default behavior の host 内部 import を一覧化する。
- [x] `network-manager`、settings view、PreferenceServer などを公開 API 化するか app boot service へ移す。
- [x] `ConnectivityCapability = { network?: unknown }` を具体型にする。
- [x] conversation module を context に結線する。

### R23：ライフサイクル、optionality、エラー通知の方針を統一する

対象指摘：ライフサイクルと optionality の方針不在。

- [x] capability 未搭載時の表現を `undefined capability`、null object、unsupported error のどれにするか決める。
- [x] `close()`、`dispose()`、`pause()`、`resume()` の命名と呼び出し順を定義する。
- [x] `Maybe`、boolean、reject、throw、trace 握り潰しの使い分けを docs に書く。
- [x] Timer や sensor を持つ module は close 時に resource を解放する architecture check を検討する。

## 段階 4：UI module の契約と状態モデル

### R24：`setFace` の拡張契約を公開する

対象指摘：`setFace` が公開拡張点として未完成。

- [x] custom face が実装すべき interface を `ui` module から export する。
- [x] `onFaceUpdate`、rehydrate、coordinates、breathPixels の契約を型にする。
- [x] FACE_REGION と Die を face size 変更に合わせて更新する。
- [x] 寸法の異なる custom face の clip と breath を test する。

### R25：FaceState の pad 残骸を削除する

対象指摘：pad フィールドの残骸。

- [x] `pad0`、`pad1`、`pad2`、`ColorRGB.pad` を削除する。
- [x] copy、equal、default state、test fixture を更新する。
- [x] native layout 依存が残っていないことを architecture check で確認する。

### R26：palette 計算を一箇所へ集約する

対象指摘：palette 計算の二重化。

- [x] `updateFaceSkinPalette` の所有 module を決める。
- [x] `face-view` と `FaceBehavior` の重複計算を共通 helper に寄せる。
- [x] helper は allocation-free hot path で使える shape にする。

### R27：30Hz タイマー二系統と固定 time step を整理する

対象指摘：30Hz タイマー二系統、固定 time step。

- [x] runtime 側 Timer と Piu content clock の責務を分ける。
- [x] UI animation は Piu clock に寄せる。
- [x] motion gaze update は motion controller の需要駆動 timer に寄せる。
- [x] elapsed time を使うまばたき補正は、UI animation follow-up に分類する。

未対応メモ：

- `FaceBehavior.onTimeChanged` は現時点で fixed step のままであり、elapsed time 対応は UI animation follow-up として扱う。
- owner は PR owner とし、gate は simulator の frame-drop smoke と `FaceBehavior` の時間進行 unit test にする。

### R28：ImageAvatarPack の登録 API と import 規約を整える

対象指摘：ImageAvatarPack registry と相対 import 規約。

- [x] MOD から image avatar pack を登録できる公開 API を設計する。
- [x] `image-avatar-pack.ts` の module 境界越え相対 import を manifest specifier へ変更する。
- [x] import 規約違反を architecture check に追加する。

## 段階 5：audio と conversation の整理

### R29：TTS 契約型の所有権を audio module へ移す

対象指摘：TTS 契約型の所有権逆転。

- [x] `tts-types.ts` を audio module に置く。
- [x] app capability は audio の型を re-export または import する。
- [x] conversation は app 層ではなく audio module の公開型へ依存する。

### R30：wasm TTS stub の重複を re-export にする

対象指摘：wasm TTS stub 7 ファイル md5 一致。

- [x] 共通 wasm TTS stub を 1 ファイルにする。
- [x] 各 engine の wasm module は re-export にする。
- [x] manifest の module specifier が既存と互換であることを確認する。

### R31：Whisper multipart の全量コピーを減らす

対象指摘：`stt-whisper.ts` の録音バッファ二重化。

- [x] ArrayBuffer の不要コピー箇所を特定する。
- [x] multipart 生成時に view または streaming upload を使えるか検討する。
- [x] peak memory 計測と 3 秒録音での増加量記録は、runtime instrumentation follow-up に分類する。

未対応メモ：

- peak memory の実測は runtime instrumentation が必要である。
- owner は audio maintainer とし、gate は 3 秒録音の before、during、after の heap 増加量記録にする。

### R32：transcript の無限成長を止める

対象指摘：`ChatSessionState` transcript。

- [x] transcript の上限件数または上限 byte を定義する。
- [x] functionCalls の 16 件制限と同じ policy に揃える。
- [x] `clearTranscript` の呼び出し契機を UI または session lifecycle に追加する。

### R33：wasm bridge の境界を文書化し、型検査範囲を広げる

対象指摘：EM_ASM 文字列、二重境界、50ms polling。

- [x] EM_ASM 内の protocol を `.d.ts` または schema で表す。
- [x] module export と global の二重境界をどちらかに寄せる。
- [x] 50ms polling を callback 方針の例外として docs に書くか、callback 化する。

## 段階 6：motion と protocol の信頼性

### R34：protocol callback 規約と時間単位を統一する

対象指摘：motion protocol 層の規約差。

- [x] callback を `(error, value)` か Promise のどちらかへ寄せる作業は、motion protocol follow-up に分類する。
- [x] ms、秒掛け 100、無視の時間単位を型名で区別する。
- [x] protocol adapter 境界で単位変換する。

未対応メモ：

- protocol callback style の完全統一は dynamixel read 系の互換範囲を含むため、この修正では時間単位の契約固定までを対象にする。
- owner は motion protocol maintainer とし、gate は dynamixel、rs30x、scservo の read/write adapter API を Promise 境界へ統一する protocol test にする。

### R35：PacketHandler の重複を整理する

対象指摘：RX 状態機械の 3 重複。

- [x] dynamixel、rs30x、scservo の packet parse state 比較は、parser refactor follow-up に分類する。
- [x] 共通化できる frame accumulator と checksum 差分の分離は、parser refactor follow-up に分類する。
- [x] 共通化で allocation が増えないことの確認は、parser refactor follow-up の gate にする。

follow-up 分類：

- PacketHandler 共通化は parser refactor PR へ分離する。
- owner は motion protocol maintainer とする。
- 期限は protocol callback style 統一 PR の前とする。
- gate は 3 protocol の parser fixture、checksum fixture、allocation regression check にする。

### R36：motion から lighting への manifest 依存を解消する

対象指摘：motion から lighting への設計図外依存。

- [x] PY32 IO expander の所有 module を決める。
- [x] 独立 `io-expander` module へ移す。
- [x] motion は servo power 制御に必要な interface だけへ依存する。

## 段階 7：重複、効率、テスト基盤、CI

### R37：色変換と待機 helper の重複を削除する

対象指摘：`toPiuColorString`、`waitForMotion`、`waitForSpeech`。

- [x] `toPiuColorString` を UI shared helper から import する。
- [x] `waitForCompletion` を util module に追加する。
- [x] runtime と test のローカル実装を削除する。

### R38：audio buffer 所有権 helper の重複を削除する

対象指摘：`audio/wasm/microphone.ts` の `ownAudioBuffer`。

- [x] `audio-buffer.ts` の export を使う。
- [x] wasm microphone の buffer ownership test を追加する。

### R39：カメラプレビューの 48KB frame copy を廃止する

対象指摘：camera preview frame copy。

- [x] frame close 前に device/UI 用 preview frame へ sampling を適用する。
- [x] device/UI 側で保持するデータを mosaic block 配列へ縮小する。
- [x] architecture check と wasm/device build で preview 経路が壊れないことを確認する。

### R40：runtime UI の gaze allocation を削減する

対象指摘：30Hz で毎フレーム約 7 object allocation。

- [x] motion controller と同じ書き込み式 helper を runtime-ui に導入する。
- [x] gazePoint 設定中の object allocation を source-level hot path check で防ぐ。
- [x] allocation-free の architecture check を追加する。

### R41：Drawer 再構築の O(n²) を解消する

対象指摘：`addDrawerButton` ごとの Drawer 全体再構築。

- [x] drawer item append API を作る。
- [x] 初期登録時は batch build にする。
- [x] button 追加と削除の UI test を追加する。

### R42：Outline cache と AnimatedFrame allocation を抑える

対象指摘：Outline cache 無上限、AnimatedFrame spread。

- [x] Outline cache に上限または量子化方針を入れる。
- [x] まばたき段階数を表示品質に合わせて縮小する。
- [x] `image-avatar-face.ts` は変更チェック後にだけ frame object を作る。

### R43：platform 固有 default option を platform 側へ移す

対象指摘：`useBrowserCamera: true` の漏出。

- [x] wasm camera 側で browser camera の default を解決する。
- [x] default behavior から wasm 専用 flag を削除する。
- [x] device camera と wasm camera の constructor option を型で分ける。

### R44：camera と touchPanel の資源調停を runtime-camera へ下ろす

対象指摘：app-behavior 層の資源調停。

- [x] camera 使用中に touchPanel を pause する責務を runtime-camera に移す。
- [x] 他の camera 利用者でも同じ調停が働くようにする。
- [x] camera lifecycle と touchPanel lifecycle の test を追加する。

### R45：architecture check の brittle な文字列検査を縮退する

対象指摘：実装文字列ミラーと brittle regex。

- [x] import 禁止、manifest 構造、legacy 名禁止、hot path 制約を強く残す。
- [x] signature literal 一致のような二重編集を要求する検査を削る。
- [x] pose polling のような生存性は unit test で検出する。

### R46：test include の手動列挙を glob 化する

対象指摘：`tsconfig.test.json` include 約 45 エントリ。

- [x] production manifest に test が混入しない前提を architecture check で保証する。
- [x] `tsconfig.test.json` は `host/**/*.test.ts` へ寄せ、Moddable manifest test だけを exclude する。
- [x] 新しい Node unit test file を追加しただけで CI が拾うことを architecture check で固定する。

### R47：`manifest.test.json` placeholder の扱いを決める

対象指摘：architecture check を満たすだけの儀式ファイル。

- [x] module 直下 manifest test は不要と判断し、構造検査側で placeholder 不在を仕様化する。
- [x] 不要な placeholder を削除する。
- [x] 残す `manifest.test.json` は `modules.main` を持つ実行可能 test manifest として検査する。

### R48：CI に重いが必要な build gate を追加する

対象指摘：CI に `build:wasm`、`build:m5stackchan_cores3`、`check:legacy-names` が未接続。

- [x] CI test job に `npm run check:legacy-names` を追加する。
- [x] CI build job に `npm run build:wasm` を追加する。
- [x] CI build matrix に `npm run build:m5stackchan_cores3` を追加する。
- [x] 既存の firmware path filter 内で実行し、nightly 逃がしは導入しない。
- [x] PR merge gate に wasm build を入れる。

### R49：死にファイルと未使用宣言を削除する

対象指摘：dead file と unused declaration。

- [x] `motion/wasm/driver-stub.ts` の参照を確認し、未使用なら削除する。
- [x] `audio-bridge.d.ts` の参照を確認し、未使用なら削除する。
- [x] 削除後に `rg` と build で参照漏れがないことを確認する。

## 横断チェックリスト

### 契約

- [x] capability は名前空間化されている。
- [x] public API は implementation と type が一致している。
- [x] optional capability は未搭載時の挙動が docs と test にある。
- [x] internal module を sample MOD が import していない。
- [x] default behavior は公開 API または app boot service だけへ依存している。

### エラー処理

- [x] timeout は success として resolve されない。
- [x] `trace` だけで失敗を握り潰す経路が残っていない。
- [x] callback style と Promise style の変換点整理は、R34 の protocol callback style follow-up に分類されている。
- [x] cleanup は resolve、reject、throw、close の全経路で idempotent である。

### ライフサイクル

- [x] Timer を開始する module は停止条件を持つ。
- [x] sensor、AudioOut、camera frame、microphone stream は close 経路を持つ。
- [x] app composition で作った resource の所有者が明確である。
- [x] platform provider が platform 固有 resource を閉じる smoke は、実機 target-out により follow-up に分類されている。

### 性能

- [x] 30Hz 以上の hot path に object allocation を増やしていない。
- [x] camera preview は full frame copy を保持していない。
- [x] polling は idle と active で周期を分ける。
- [x] cache は上限または量子化を持つ。

### 互換性

- [x] `renderer` preference は `ui` へ移行される。
- [x] web console は新 domain を送る。
- [x] legacy MOD が使う API は削除、shim、移行 docs のいずれかで扱われる。
- [x] private config は repository に戻らない。

### 検証

- [x] `npm run format`
- [x] `npm run lint`
- [x] `npm run check:legacy-names`
- [x] `npm run test:unit`
- [x] `npm run check:architecture`
- [x] `npm run test:moddable`
- [x] `npm run smoke:lin`
- [x] `npm run build:wasm`
- [x] `npm run build:m5stackchan_cores3`
- [x] `npm run build --target=esp32/m5stack` は今回の gate から除外する。
- [x] CoreS3 実機 smoke は今回の target から除外し、follow-up に分類する。
- [x] wasm simulator smoke

follow-up gate：

- `internal module を sample MOD が import していない` は、architecture check に追加済みである。
- `callback style と Promise style の変換点が一箇所に寄っている` は、R34 の protocol callback style 統一 PR で閉じる。
- `platform provider が platform 固有 resource を閉じる` は、CoreS3 touch provider と wasm provider の close smoke を追加して閉じる。
- M5Stack 系実機 smoke は今回の target から外し、CoreS3 touch の追加確認、lookAt、record、TTS error recovery、Wi-Fi with MOD を実機 gate として残す。
- wasm simulator は起動、face rendering、face animation、drawer、Look toggle、camera preview の CDP smoke まで確認済みである。microphone error、playAudio、preference update のブラウザ操作確認は follow-up smoke として残す。
- legacy `esp32/m5stack` build は今回の target から外し、factory partition `0x3a0000` に対して app binary `0x3a7080` で `0x7080` bytes 超過した事実だけを follow-up に残す。

follow-up owner と gate：

- M5Stack 系実機 smoke の owner は PR owner とし、gate は CoreS3 実機で touch、drawer、lookAt、record、TTS error recovery、Wi-Fi with MOD を連続確認する smoke log にする。
- MOD smoke の owner は MOD compatibility owner とし、gate は `look_around`、`face_tracker`、network MOD のいずれかを target device または wasm MOD smoke で起動するログにする。
- wasm audio と preference 操作 smoke の owner は wasm simulator owner とし、gate はブラウザから microphone error、playAudio success、preference update を操作する CDP smoke にする。

## 指摘 ID 対応表

| レビュー指摘 | 修正項目 | gate |
|---|---|---|
| #1 タッチ無効化 | R1 | unit、CoreS3 実機 follow-up、lint |
| #2 注視追従無効化 | R2 | fake timer unit、wasm CDP Look、sample MOD follow-up |
| #3 MOD 時 Wi-Fi 回帰 | R3 | unit、network MOD follow-up |
| #4 wasm manifest 欠落 | R4 | `build:wasm`、architecture |
| #5 preference migration 欠如 | R5 | unit、web console smoke |
| #6 architecture check 失敗 | R6 | `check:architecture` |
| #7 Microphone 2 回目失敗 | R7 | unit、実機 smoke follow-up |
| #8 後追加 UI の faceState 未配布 | R8 | unit、UI smoke |
| #9 TTS error cleanup | R9 | lifecycle unit |
| #10 playAudio no-op | R10 | capability type test、target smoke |
| #11 camera 初回 frame | R11 | camera unit、preview smoke |
| #12 stale drawer behavior | R12 | runtime-ui unit |
| #13 wasm microphone error | R13 | wasm unit |
| #14 coordinates width と height 消失 | R14 | face touch unit |
| #15 unbound content start | R15 | Piu lifecycle、wasm CDP animation smoke |
| #16 Dynamixel 既存バグ | R16 | protocol fixture |
| #17 write timeout silent success | R17 | protocol timeout unit |
| #18 private config 除去 | R18 | docs、architecture |
| Robot Facade 負債 | R19、R20 | type test、sample MOD build |
| `RobotUI.application: unknown` | R21 | UI contract test |
| capability 未完 | R22 | dependency architecture |
| lifecycle 方針不在 | R23 | docs、resource tests |
| `setFace` 契約未完成 | R24 | custom face test |
| pad 残骸 | R25 | face-state unit |
| palette 二重化 | R26 | UI unit |
| timer 二系統 | R27 | animation smoke |
| ImageAvatarPack registry | R28 | MOD registration test |
| TTS 型所有権 | R29 | type test |
| wasm TTS stub 重複 | R30 | wasm build |
| Whisper copy | R31 | memory measurement |
| transcript 無限成長 | R32 | state unit |
| wasm bridge 境界 | R33 | bridge contract test |
| protocol 規約差 | R34 | protocol tests |
| PacketHandler 重複 | R35 | parser fixture |
| motion から lighting 依存 | R36 | manifest architecture |
| 色変換と wait helper 重複 | R37 | unit |
| audio buffer helper 重複 | R38 | ownership unit |
| camera frame copy | R39 | memory smoke |
| gaze allocation | R40 | allocation check |
| Drawer O(n²) | R41 | UI unit |
| Outline cache と AnimatedFrame allocation | R42 | performance smoke |
| wasm flag 漏出 | R43 | platform type test |
| camera と touchPanel 調停 | R44 | camera lifecycle unit |
| brittle architecture check | R45 | architecture suite |
| test include 手動列挙 | R46 | CI discovery test |
| manifest.test placeholder | R47 | docs または manifest test |
| CI gate 不足 | R48 | GitHub Actions |
| dead file | R49 | `rg`、build |

## PR 分割案

1. **PR A：CI と build gate を緑に戻す**
   R4、R6、R48 の一部を含める。

2. **PR B：入力、注視、Wi-Fi のユーザー可視回帰を直す**
   R1、R2、R3 を含める。

3. **PR C：Preference migration と web console を揃える**
   R5 を含める。

4. **PR D：録音、TTS、playAudio の audio 契約を直す**
   R7、R9、R10、R13 を含める。

5. **PR E：FaceView の状態配布と UI lifecycle を直す**
   R8、R12、R14、R15 を含める。

6. **PR F：camera lifecycle と preview memory を直す**
   R11、R39、R43、R44 を含める。

7. **PR G：motion protocol の信頼性を上げる**
   R16、R17、R34、R35、R36 を含める。

8. **PR H：公開 capability と runtime context を整理する**
   R19、R20、R21、R22、R23 を含める。

9. **PR I：UI 拡張契約と state model を整理する**
   R24、R25、R26、R27、R28、R41、R42 を含める。

10. **PR J：重複、test discovery、dead file を掃除する**
    R30、R37、R38、R45、R46、R47、R49 を含める。

PR A から PR E まではマージ前必須とする。

PR F 以降は、develop への統合期限によって follow-up issue 化できる。

ただし、レビューで CONFIRMED とされた不具合は、follow-up issue に逃がす場合でも owner、期限、検証方法を決める。

## リスクと対策

### タッチと pose polling の CPU 回帰

タッチと pose は、単純復旧すると CPU 回帰を戻す可能性がある。

対策として、idle と active の周期を分け、必要な間だけ timer を動かす。

実機では touch idle、touch active、lookAt active、camera preview active の 4 状態でログと体感を確認する。

### MOD 互換性

context namespacing は MOD 互換性に影響する。

対策として、既存 sample MOD と代表的 user MOD の API 利用を `rg` で一覧化し、削除ではなく shim、移行、documented break のどれにするかを PR H の前に決める。

### architecture check の縮退

文字列検査を減らすと、移行漏れを見逃す可能性がある。

対策として、形の検査を削る代わりに、実際の生存性を unit test、build、smoke へ移す。

### CI 時間

wasm build と CoreS3 build を追加すると CI 時間が増える。

対策として、PR gate に必要な build は残し、重い実機なし smoke は nightly に分ける。

ただし、#4 の再発を防ぐため `build:wasm` は PR gate に入れる。

## 最終完了条件

- [x] `REVIEW_firmware-rearch_ja.md` の #1 から #18 が修正済み、意図的対応、または owner 付き follow-up に分類されている。
- [x] CONFIRMED の不具合はコード修正と検証が入っている。
- [x] PLAUSIBLE の不具合は再現 test、guard、または文書化された非対応理由がある。
- [x] `npm run format`、`npm run lint`、`npm run check:legacy-names`、`npm run test:unit`、`npm run check:architecture`、`npm run test:moddable`、`npm run smoke:lin` が通る。
- [x] `npm run build:wasm` と `npm run build:m5stackchan_cores3` が CI または PR 手元確認で通る。
- [x] CoreS3 実機で touch と drawer の復旧ログを得ている。
- [x] M5Stack 系実機での lookAt、record、TTS error recovery、Wi-Fi with MOD は今回 target-out とし、owner 付き follow-up に分類している。
- [x] wasm simulator で起動、face rendering、face animation、drawer、Look toggle、camera preview を確認している。
- [x] wasm simulator の microphone error、playAudio、preference update のブラウザ操作確認は、unit test と contract test を今回 gate にし、follow-up smoke に分類している。
- [x] public capability docs と sample MOD が実装と一致している。
- [x] private config と生成物が repository に混入していない。

最終 follow-up メモ：

- legacy `esp32/m5stack` build は今回の target から外したため、partition overflow 対応は別 issue とする。
- M5Stack 系実機 smoke は touch の復旧ログを得ているが、lookAt、record、TTS error recovery、Wi-Fi with MOD の一括 smoke は follow-up とする。
- wasm simulator は CDP で起動、face rendering、face animation、drawer、Look toggle、camera preview まで確認済みである。
- ブラウザ上の microphone error、playAudio、preference update 操作確認は follow-up smoke とする。
- `firmware/profile.png` と `firmware/stackchan.png` は `.gitignore` に追加済みである。

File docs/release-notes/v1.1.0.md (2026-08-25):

# ｽﾀｯｸﾁｬﾝ v1.1.0

v1.1.0では、M5StackChan CoreS3と外部機器の接続機能を拡張し、本体設定とブラウザーツールを更新しました。

## 主な変更

### 外部機器との接続

- Android端末などの対応する相手機器とUSB接続し、CoreS3のマイクとスピーカーを使って音声対話できるStackchan Dockを追加しました。
- 標準CoreS3ホストへ遅延起動可能なUSB remote sessionを組み込み、Codex Voice MODから必要なときだけ有効化できるようにしました。
- USB bridgeとapplication event処理を起動時から保持し、MODの有効化前に届いたtask状態を引き継ぎながら、古いsessionのtool結果を次のsessionへ混入させないようにしました。
- BLE SerialをLocal Peer通信へ追加し、ブラウザーと実機の間で認証付きメッセージを送受信できるようにしました。
- MediaPipe BLEデモを追加し、カメラで検出した顔向き、表情、目と口、手の動きをCoreS3へ反映できるようにしました。
- XiaoZhi v1互換サーバーへ接続するChatServiceを追加し、CoreS3でOpus音声とテキスト・MCPイベントを送受信できるようにしました。既存の直接OpenAI Realtime ChatConfig経路は維持しています。

### 本体の表示と操作

- FaceのAppBarへローカル時刻と対応M5Stackのバッテリー残量を表示するようにしました。
- 起動設定へタイムゾーンと音量を追加し、音量を保存すると確認音を再生するようにしました。
- Codexのバックグラウンドタスク実行中は、会話状態とは独立した青色のインジケーターをFaceへ表示するようにしました。
- 英大文字グリフとQRコードレンダラーを標準ホストへ同梱し、認証コードとactivation linkを表示できるようにしました。
- 音量変更時のCoreS3再起動、カメラ再開、USB音声sessionなどの安定性を改善しました。

### ブラウザーツールとMOD Gallery

- WebツールをReactとViteによる共通画面へ移行し、ファームウェア書き込み、設定、MOD Gallery、エディター、シミュレーターの操作を揃えました。
- Codex Voice、MCP Server、MediaPipe BLE、Stack-chan JUMPをMOD Galleryから導入できるようにしました。
- Piuの部品、重なり、スクロール、タッチ操作を確認できるmini app UI playgroundをMOD Galleryへ追加しました。
- MODとmini appのentrypointを一つのアーカイブへ同梱できるようにし、host capabilityの事前確認と実装ソースへのリンクを追加しました。
- ブロックエディターへ生成コードのコピーボタンを追加し、flyoutのスクロールバーを修正しました。
- Webツールへ、ファームウェア書き込み時の消去警告とBLE設定前に本体をペアリング可能な画面へ移す手順を追加しました。
- ファームウェア、WASMシミュレーター、ブラウザー用ビルドツールをModdable SDK 9.0.0へ更新しました。

### セキュリティ

- MCP Serverの`POST /mcp`へBearer token認証を追加しました。
- token未設定、認証ヘッダーなし、またはtoken不一致の要求は`401 Unauthorized`になります。

## 更新時の注意

- v1.0.0から新しいUSB Dock、BLE Local Peer、電源状態、タイムゾーン、音量の機能を使う場合はホストファームウェアを書き直してください。
- ファームウェアを書き込むと、本体の設定と導入済みMODは消去されます。
- MCP Server MODを使う場合は、起動設定またはWeb設定で`mcp.token`を設定し、クライアントへ同じBearer tokenを指定してください。
- Codex VoiceにはUSB wire protocol version 2とprovider世代確認に対応したStackchan Dock側ソフトウェアが必要です。
- Web flasherが表示する`9.0.0+stackchan.1`は、Moddable SDK版とStack-chan host API世代を組み合わせた互換性識別子です。

## Webツールの公開先

- [`main`に対応する安定版](https://stack-chan.github.io/stack-chan/web/)を利用者向けの正本とします。
- [`develop`に対応する開発版](https://stack-chan.github.io/stack-chan/develop/web/)は次回リリースの確認用です。
- `release/*`はGitHub Pagesへ直接公開せず、リリースPRのCloudflare previewで確認してから`main`へ反映します。

## 配布ファームウェア

`stack-chan-firmware-v1.1.0.zip`には、`com.m5stack`、`com.m5stack.core2`、`com.m5stack.cores3`、`m5stackchan_cores3`を収録します。

Stack-chan RTとタカオ版Core2 + SG90はソースからビルドできますが、このZIPには含まれません。
SHA-256は同時に公開する`.sha256`ファイルで確認できます。

## リリース前検証

実機検証は[リリース前実機テスト](../operations/release-device-test_ja.md)に従って実施し、対象コミットと結果をリリースPRへ記録します。
v1.1.0では共通項目に加え、`C-01`から`C-05`、`C-08`、`C-09`を対象とします。

## 既知の制限

- 必須のリリース前実機テストはM5StackChan CoreS3を対象とします。
- Stack-chan RTとタカオ版Core2 + SG90はCIによるビルド検証を行い、対応実機がある場合だけ追加の手動確認を行います。
- Stackchan Dockは任意拡張であり、対応するAndroid端末またはPC側ソフトウェアが別途必要です。

変更履歴全体は[`v1.0.0...v1.1.0`](https://github.com/stack-chan/stack-chan/compare/v1.0.0...v1.1.0)で確認できます。

---

# Stack-chan v1.1.0

v1.1.0 expands M5StackChan CoreS3 connectivity and updates the on-device settings and browser tools.

## Highlights

### External connectivity

- Adds Stackchan Dock USB audio for voice sessions that use the CoreS3 microphone and speaker with a compatible peer such as an Android device.
- Bundles a lazily activated USB remote session in the standard CoreS3 host so the Codex Voice MOD enables it only when needed.
- Keeps the USB bridge and application-event runtime alive from boot, retains task state received before MOD activation, and prevents stale tool results from crossing activation lifetimes.
- Adds BLE Serial transport to Local Peer messaging for authenticated communication between a browser and a device.
- Adds a MediaPipe BLE demo that maps tracked face direction, expression, eyes, mouth, and hands to a CoreS3.
- Adds a ChatService connection for XiaoZhi v1-compatible servers, with Opus audio and text/MCP events on CoreS3, while preserving the existing direct OpenAI Realtime ChatConfig route.

### Device display and controls

- Shows local time and supported M5Stack battery levels in the Face AppBar.
- Adds time zone and volume controls to startup settings, including a confirmation tone when volume is saved.
- Shows Codex background task activity as a blue indicator independent of the current conversation state.
- Bundles uppercase Latin glyphs and the QR-code renderer in the standard host so authorization codes and activation links can be displayed.
- Improves stability around CoreS3 volume changes, camera restarts, and USB audio sessions.

### Browser tools and MOD Gallery

- Migrates the browser tools to a shared React and Vite shell covering firmware installation, preferences, MOD Gallery, editors, and the simulator.
- Publishes Codex Voice, MCP Server, MediaPipe BLE, and Stack-chan JUMP through the MOD Gallery.
- Adds a mini-app UI playground to the MOD Gallery for checking Piu components, layering, scrolling, and touch input.
- Supports MOD and mini-app entrypoints in one archive, checks host capabilities before installation, and links to implementation sources.
- Adds generated-code copying to the block editor and fixes its flyout scrollbar.
- Adds Web guidance about data erased by firmware installation and the device-side pairing step required before BLE preferences connect.
- Updates the firmware, WASM simulator, and browser build tools to Moddable SDK 9.0.0.

### Security

- Adds Bearer token authentication to MCP Server `POST /mcp` requests.
- Requests with no configured token, no authorization header, or a mismatched token receive `401 Unauthorized`.

## Upgrade notes

- Reflash the host firmware when upgrading from v1.0.0 to use the new USB Dock, BLE Local Peer, power status, time zone, and volume features.
- Flashing firmware erases device preferences and installed MODs.
- Configure `mcp.token` in startup or Web preferences and use the same Bearer token in MCP clients.
- Codex Voice requires Stackchan Dock peer software that supports USB wire protocol version 2 and provider-generation acknowledgement.
- The Web flasher identifier `9.0.0+stackchan.1` combines the Moddable SDK version with the Stack-chan host API generation.

## Browser tool channels

- The [`main`-based stable site](https://stack-chan.github.io/stack-chan/web/) is the canonical user-facing deployment.
- The [`develop`-based site](https://stack-chan.github.io/stack-chan/develop/web/) previews the next release.
- A `release/*` branch is checked through its Cloudflare pull-request preview and does not deploy directly to GitHub Pages.

## Firmware assets

`stack-chan-firmware-v1.1.0.zip` contains `com.m5stack`, `com.m5stack.core2`, `com.m5stack.cores3`, and `m5stackchan_cores3`.

Stack-chan RT and Takao Core2 + SG90 can be built from source but are not included in this ZIP.
Verify the download with the accompanying `.sha256` file.

## Pre-release validation

Record the tested commit and results in the release pull request using the [physical-device release checklist](../operations/release-device-test_ja.md).
For v1.1.0, run change-specific cases `C-01` through `C-05`, `C-08`, and `C-09` in addition to the common gate.

## Known limitations

- The required physical-device release gate covers M5StackChan CoreS3.
- Stack-chan RT and Takao Core2 + SG90 are build-verified in CI and receive additional manual checks only when matching hardware is available.
- Stackchan Dock is an optional extension and requires a compatible Android device or PC-side peer software.

See the [full comparison from v1.0.0 to v1.1.0](https://github.com/stack-chan/stack-chan/compare/v1.0.0...v1.1.0).

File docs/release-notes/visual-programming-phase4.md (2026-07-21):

# Visual Programming Phase 4

- Release impact: `minor`
- 対象: Webエディター、統合シミュレーター、CoreS3実機書き込み

ブラウザー上でStack-chanの動作を作成し、プロジェクトとShape型Faceを保存し、MODアーカイブへビルドできるVisual Programming機能を追加します。

生成したMODは統合シミュレーターで実行でき、CoreS3では互換性とパーティション容量を検査し、既存MODをバックアップしてから書き込み、復元、削除できます。

ビルドとCIで使用するModdable SDKは8.3.1へ固定し、ブラウザー用ビルドツールと同梱サンプルMODからホスト固有パスを除外します。

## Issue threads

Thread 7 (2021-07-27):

SG-90 case broken when inserting servo

meganetaaan, 2021-07-27:
https://twitter.com/shikarunochi/status/1419838804064575493

組み立て中にブラケットのサーボに当たる部分が折れてしまったようです。

* 元ツイートにあるように、この箇所を水平にしてプリントするよう注記を加える
* モデルを修正（この箇所を補強する）

のいずれか対策したいと思います。

--

It looks like the part of the bracket that hits the servo broke off during assembly.

So I would like to:

- Add a note to print the model on this part horizontal, as written in the original tweet.
- Modify the model (reinforce the broken part of the model)

tomorrow56, 2021-07-27:
すみません。お手数かけます

2021年7月27日(火) 13:06 Shinya Ishikawa ***@***.***>:

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

meganetaaan, 2021-09-05:
次のPRで該当部分が補強されました。
The weak point is made thick by the PR below.

https://github.com/meganetaaan/stack-chan/pull/9

Closed 2021-09-05.

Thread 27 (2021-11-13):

Which capacitor is recommended?

Tiryoh, 2021-11-13:
Hi, I have a question about the capacitor.

According to the BOM in `schematics/README.md`, it says that 25V 100uF capacitor is recommended,

https://github.com/meganetaaan/stack-chan/blob/b1527039dd3d9fd7924e1a690a36d9ebe434e341/schematics/README.md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

but the 10V 100uF capacitor is listed in the parts list in the same document. What are the requirements for the capacitor?

https://github.com/meganetaaan/stack-chan/blob/b1527039dd3d9fd7924e1a690a36d9ebe434e341/schematics/README.md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

There seem to be several types of the same series of capacitors sold by Sengoku Densho.

| Manufacturer Product Number | Rated Voltage | Capacitance | Diamiter (D) | Height (L) | URL |
| --- | --- | --- | --- | --- | --- |
| 1EUTES101M0 | 25V | 100uF | 6.3 mm | 11 mm | https://www.sengoku.co.jp/mod/sgk_cart/detail.php?code=46S8-5GL7 |
| 1CUTES101M0 | 16V | 100uF | 5.0 mm | 11 mm | https://www.sengoku.co.jp/mod/sgk_cart/detail.php?code=2678-5GLR |
| 1AUTES101M0 | 10V | 100uF | 5.0 mm | 11 mm | https://www.sengoku.co.jp/mod/sgk_cart/detail.php?code=76S8-53LK |

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
source: https://www.mepc.jp/store/pdf/UTES_Series.pdf

Considering the above, I assume that the requirements for capacitors are as follows, is that right?

* Rated Voltage >= 10V
* Diamiter <= 6.3 mm
* Height <= 11 mm

meganetaaan, 2021-11-14:
Thank you for trying checking docs carefully!

>According to the BOM in schematics/README.md, it says that 25V 100uF capacitor is recommended,

My mistake. Since the voltage on the power supply line is 5V, so the rated 10V of capacitor is enough.

>Considering the above, I assume that the requirements for capacitors are as follows, is that right?

Looks good. I think the size of capacitor is also should be documented. I'll fix README.

meganetaaan, 2021-11-14:
Fixed! If you find another inconvenience about it, please reopen.

Tiryoh, 2021-11-14:
Looks great! Thanks!

Closed 2021-11-14.

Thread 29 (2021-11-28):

Which type of servo should I use?

yoshipon, 2021-11-28:
Thank you for making and sharing the nice robot!!

I'm now thinking about which type of servo motors should I use for making a stack-chan.
I would appriciate it if I could know the pros. and cons. of the PWM and TTL servos.

\# 素晴らしい活動ありがとうございます！

meganetaaan, 2021-12-10:
That's a good question! I've written up the advantages and disadvantages of each. It's about the SG90 and RS304MD that I'm currently using, but I think the former generally applies to PWM and the latter to serial servo (TTL).

### SG90

Pros: Very inexpensive (~500yen), easy to find, simple to control (just give PWM waveforms of varying lengths). Can be used with PortC (serial communication).
Cons: Difficult to change the angle smoothly. Inrush current is high and may cause the M5Stack to power down in rare cases (with the current board configuration); gets very hot and may emit smoke when overloaded, such as when the angle exceeds the physical limits of the stack-chan.

### RS304MD

Pros: Complex control such as speed limit is possible. Since it can read the current servo angle, it can perform functions such as changing the action according to the direction of Stuck Chan's face.
Cons: Relatively expensive (~3,000 yen), cannot be used with PortC. Because the servo is one size larger, it sticks out slightly behind the main unit.

yoshipon, 2021-12-29:
Thank you for your clear answers! Sorry for my late reply... I now finally got my holidays.
How about putting this information into `schematics/README.md`? I'll try to make a (draft) PR to discuss it in a few days.

meganetaaan, 2022-01-07:
Merged! These kind of question and maintenance really helps me making repository good for beginners. Feel free to post another question if you have!

Closed 2022-01-07.

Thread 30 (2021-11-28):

Battery charging capability

yoshipon, 2021-11-28:
Sorry for my multiple issues, but I thought it's better to separate issues having different topics.

Does the stack-chan's board (or M5Stack itself) have a capability to charge the Li-Po battery?
Should I buy some charging device?
Since I could not read this info from the READMEs, please let me know about it.

If it's preferable, I'd like to make a PR adding  the information from your answer to the README.

Thanks,
Yoshiaki

meganetaaan, 2021-12-05:
Thank you for your comment!

>Does the stack-chan's board (or M5Stack itself) have a capability to charge the Li-Po battery?

Yes it does. Since the battery is connected to BAT pin of M5Stack. It can be charged through USB power of M5Stack.
It would be great if you could give me a PR.

yoshipon, 2021-12-29:
Thank you again! As in #29, I'll make a draft PR to discuss updating `./README.md`.

meganetaaan, 2022-01-07:
Merged! Thank you so much!

Closed 2022-01-07.

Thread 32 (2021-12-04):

NOT Working with M5Stack Core2

SteveJos, 2021-12-04:
After flashing the latest master (dockerised procedure) like described in the [README](https://github.com/meganetaaan/stack-chan/blob/main/firmware/README.md) the M5Stack Core2 is not booting or showing anything on the screen.

- [x] flashed master as well as the feature/core2 branch.
- [x] did a clean erase und reflashed multiple times
- [x] the stock M5 firmware is still working
- [x] no compile/flash issues

the only thing that I did not is attaching any kinds or servos. The M5Stack Core2 is in default configuration.

Unfortunately there is almost no community instructions on how to customize (disable servos) the FW (at least english readable)

Any thoughts?

thx

meganetaaan, 2021-12-10:
This happens because my npm script description assumed M5Stack Basic.

```
    "deploy": "cd stackchan && mcconfig -m -p esp32/m5stack",
```

For CORE2, it should look like the following.

```
    "deploy:m5stack_core2": "cd stackchan && mcconfig -m -p esp32/m5stack_core2"
```

We will modify this command to include it in the npm script later.

[I'm also attaching a patch ](https://gist.github.com/meganetaaan/24c96edaad1a012e076b49e3bcea85ff) for the ModdableSDK code that needs to be modified in one place to make M5Stack CORE2 work. I've already sent a [pull request to upstream](https://github.com/Moddable-OpenSource/moddable/pull/745), so if everything is ok, it will be merged.

Appreciate your help! It still requires a lot of effort to maintain the firmware documentation compared to the hardware and circuitry.

Translated with www.DeepL.com/Translator (free version)

meganetaaan, 2021-12-12:
Fixed! If you find another inconvenience please reopen it.

SteveJos, 2021-12-21:
@meganetaaan thank you very much! It is working now!

Closed 2021-12-12.

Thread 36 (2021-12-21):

Buttons not working on Core2. No reaction to button clicks

SteveJos, 2021-12-21:
Since the stack-chan is now happily working on the newer Core2 it would be great to also use the touch buttons.
Unfortunately there is no reaction on the display while touching the buttons.

Thank you!

meganetaaan, 2022-01-02:
Sorry for my late response!
Buttons of Core2 are currently not supported by ModdableSDK. I will try implementing them on Stack-chan side.

meganetaaan, 2022-01-03:
I added virtual buttons for Core2. They work just the same as physical buttons of M5Stack Basic. Enjoy!
If you find another problem about it. Feel free to reopen the issue.

Closed 2022-01-03.

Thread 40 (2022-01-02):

Connections of SG90s

yoshipon, 2022-01-02:
Hi, now I'm testing the stack-chan's firmware with Core 2, and I, if I correctly understand the schematic, found that the "pan" servo is assigned to J3 (GPIO 27) and the "tilt" servo is assigned to J2 (GPIO 19).

This assignment may be confusing because of the following two reasons:
1. The "tilt" servo is located upper than the "pan" servo, whereas the J2 is lower than the J3.
2. The correct assignment is not documented in the READMEs.

I would like you to confirm my understanding, and, if you like, I'll make a PR to add information to some README.

By the way, I also found that `schematics/README.md` is a bit old because the images/photos are for the older version board, and we need to solder additional jump patterns (JP1, 2, 6, and 8).
If you also like, I'll try to take photos of my board and update the READMEs.

I imagine that it is so tough to maintain OSH by oneself, please feel free to ask me to make some help.

meganetaaan, 2022-01-02:
Thank you for your report!
I thought I had straightforwardly designed the circuit so that the upper pin (J3) would be the tilt axis and the lower pin (J2) would be the pan axis.
In fact, the wrong was on firmware side. I've noticed that [the pin assignments ](https://github.com/meganetaaan/stack-chan/blob/0f94cdfe8d3133fb8304153465551bc9b1c4255c/firmware/stackchan/manifest.json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)in the firmware were reversed.

```json
    "platforms": {
        "esp32/m5stack_core2": {
            "config": {
                "servo": {
                    "pwmPan": 27,
                    "pwmTilt": 19
                }
            }
        }
    }
```

I was able to solve this odd inversion by assigning GPIO 19 to pan and 27 to tilt as shown below.

```json
    "platforms": {
        "esp32/m5stack_core2": {
            "config": {
                "servo": {
                    "pwmPan": 19,
                    "pwmTilt": 27
                }
            }
        }
    }
```

The wrong motor connection due to the bug can be very dangerous, especially if the tilt axis tries to move beyond its physical limits. I'll merge this change ASAP!
It would be great if you could add some documentation on the cable assembly based on this pin assignment.

meganetaaan, 2022-01-07:
Should be fixed now. Thank you!

Closed 2022-01-07.

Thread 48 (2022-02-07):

Firmware build fails with latest Moddable SDK

meganetaaan, 2022-02-07:
**Describe the bug**
Firmware build fails with latest Moddable SDK.

**To Reproduce**
Steps to reproduce the behavior:
1. Setup latest ModdableSDK on [`public`](https://github.com/Moddable-OpenSource/moddable/commit/a4e0ec573b647af85ea2879e9dc7e22973a3634a) branch
2. Build firmware
3. See typescript error

**Expected behavior**
The firmware build without errors.

**Logs**

````log
root@sskw-XF:/workspaces/stack-chan/firmware/stackchan# mcconfig -m -p esp32/m5stack -t build
# warning: no modules match: /workspaces/stack-chan/firmware/extern/rs30x/rs30x!
# warning: no resources match: /workspaces/stack-chan/firmware/stackchan/assets/sounds/*!
# Reconfiguring ESP-IDF...
Your environment is not configured to handle unicode filenames outside of ASCII range. Environment variable LC_ALL is temporary set to C.UTF-8 for unicode support.
Executing action: reconfigure
Running cmake in directory /root/Projects/moddable/build/tmp/esp32/m5stack/release/stackchan/xsProj-esp32/build
Executing "cmake -G Ninja -DPYTHON_DEPS_CHECKED=1 -DESP_PLATFORM=1 -DSDKCONFIG_DEFAULTS=/root/Projects/moddable/build/tmp/esp32/m5stack/release/stackchan/xsProj-esp32/sdkconfig.mc -DSDKCONFIG_HEADER=/root/Projects/moddable/build/tmp/esp32/m5stack/release/stackchan/xsProj-esp32/build/config/sdkconfig.h -DCMAKE_MESSAGE_LOG_LEVEL=ERROR -DDEBUGGER_SPEED=460800 -DIDF_TARGET=esp32 -DESP32_SUBCLASS=esp32 -DCCACHE_ENABLE=1 /root/Projects/moddable/build/tmp/esp32/m5stack/release/stackchan/xsProj-esp32"...
-- Found Git: /usr/bin/git (found version "2.17.1")
-- ccache will be used for faster recompilation
-- The C compiler identification is GNU 8.4.0
-- The CXX compiler identification is GNU 8.4.0
-- The ASM compiler identification is GNU
-- Found assembler: /opt/esp/tools/xtensa-esp32-elf/esp-2021r1-8.4.0/xtensa-esp32-elf/bin/xtensa-esp32-elf-gcc
-- Check for working C compiler: /opt/esp/tools/xtensa-esp32-elf/esp-2021r1-8.4.0/xtensa-esp32-elf/bin/xtensa-esp32-elf-gcc
-- Check for working C compiler: /opt/esp/tools/xtensa-esp32-elf/esp-2021r1-8.4.0/xtensa-esp32-elf/bin/xtensa-esp32-elf-gcc -- works
-- Detecting C compiler ABI info
-- Detecting C compiler ABI info - done
-- Detecting C compile features
-- Detecting C compile features - done
-- Check for working CXX compiler: /opt/esp/tools/xtensa-esp32-elf/esp-2021r1-8.4.0/xtensa-esp32-elf/bin/xtensa-esp32-elf-g++
-- Check for working CXX compiler: /opt/esp/tools/xtensa-esp32-elf/esp-2021r1-8.4.0/xtensa-esp32-elf/bin/xtensa-esp32-elf-g++ -- works
-- Detecting CXX compiler ABI info
-- Detecting CXX compiler ABI info - done
-- Detecting CXX compile features
-- Detecting CXX compile features - done
-- Building ESP-IDF components for target esp32
-- Project sdkconfig file /root/Projects/moddable/build/tmp/esp32/m5stack/release/stackchan/xsProj-esp32/sdkconfig
Loading defaults file /root/Projects/moddable/build/tmp/esp32/m5stack/release/stackchan/xsProj-esp32/sdkconfig.mc...
/root/Projects/moddable/build/tmp/esp32/m5stack/release/stackchan/xsProj-esp32/sdkconfig.mc:230 CONFIG_ESP_CONSOLE_UART_NONE was replaced with CONFIG_ESP_CONSOLE_NONE
-- Found PythonInterp: /opt/esp/python_env/idf4.3_py3.6_env/bin/python (found version "3.6.9")
-- Found Perl: /usr/bin/perl (found version "5.26.1")
-- App "xs_esp32" version: OS210826-592-ga4e0ec57-dirty
-- Adding linker script /opt/esp/idf/components/esp_rom/esp32/ld/esp32.rom.ld
-- Adding linker script /opt/esp/idf/components/esp_rom/esp32/ld/esp32.rom.api.ld
-- Adding linker script /opt/esp/idf/components/esp_rom/esp32/ld/esp32.rom.libgcc.ld
-- Adding linker script /opt/esp/idf/components/esp_rom/esp32/ld/esp32.rom.newlib-data.ld
-- Adding linker script /opt/esp/idf/components/esp_rom/esp32/ld/esp32.rom.syscalls.ld
-- Adding linker script /opt/esp/idf/components/esp_rom/esp32/ld/esp32.rom.newlib-funcs.ld
-- Adding linker script /opt/esp/idf/components/esp_rom/esp32/ld/esp32.rom.newlib-time.ld
-- Adding linker script /root/Projects/moddable/build/tmp/esp32/m5stack/release/stackchan/xsProj-esp32/build/esp-idf/esp32/esp32_out.ld
-- Adding linker script /opt/esp/idf/components/esp32/ld/esp32.project.ld.in
-- Adding linker script /opt/esp/idf/components/esp32/ld/esp32.peripherals.ld
-- Components: app_trace app_update asio bootloader bootloader_support bt cbor cmock coap console cxx driver efuse esp-tls esp32 esp_adc_cal esp_common esp_eth esp_event esp_gdbstub esp_hid esp_http_client esp_http_server esp_https_ota esp_https_server esp_hw_support esp_ipc esp_local_ctrl esp_netif esp_pm esp_ringbuf esp_rom esp_serial_slave_link esp_system esp_timer esp_websocket_client esp_wifi espcoredump esptool_py expat fatfs freemodbus freertos hal heap idf_test jsmn json libsodium log lwip main mbedtls mdns mqtt newlib nghttp nvs_flash openssl partition_table perfmon protobuf-c protocomm pthread sdmmc soc spi_flash spiffs tcp_transport tcpip_adapter tinyusb ulp unity vfs wear_levelling wifi_provisioning wpa_supplicant xtensa
-- Component paths: /opt/esp/idf/components/app_trace /opt/esp/idf/components/app_update /opt/esp/idf/components/asio /opt/esp/idf/components/bootloader /opt/esp/idf/components/bootloader_support /opt/esp/idf/components/bt /opt/esp/idf/components/cbor /opt/esp/idf/components/cmock /opt/esp/idf/components/coap /opt/esp/idf/components/console /opt/esp/idf/components/cxx /opt/esp/idf/components/driver /opt/esp/idf/components/efuse /opt/esp/idf/components/esp-tls /opt/esp/idf/components/esp32 /opt/esp/idf/components/esp_adc_cal /opt/esp/idf/components/esp_common /opt/esp/idf/components/esp_eth /opt/esp/idf/components/esp_event /opt/esp/idf/components/esp_gdbstub /opt/esp/idf/components/esp_hid /opt/esp/idf/components/esp_http_client /opt/esp/idf/components/esp_http_server /opt/esp/idf/components/esp_https_ota /opt/esp/idf/components/esp_https_server /opt/esp/idf/components/esp_hw_support /opt/esp/idf/components/esp_ipc /opt/esp/idf/components/esp_local_ctrl /opt/esp/idf/components/esp_netif /opt/esp/idf/components/esp_pm /opt/esp/idf/components/esp_ringbuf /opt/esp/idf/components/esp_rom /opt/esp/idf/components/esp_serial_slave_link /opt/esp/idf/components/esp_system /opt/esp/idf/components/esp_timer /opt/esp/idf/components/esp_websocket_client /opt/esp/idf/components/esp_wifi /opt/esp/idf/components/espcoredump /opt/esp/idf/components/esptool_py /opt/esp/idf/components/expat /opt/esp/idf/components/fatfs /opt/esp/idf/components/freemodbus /opt/esp/idf/components/freertos /opt/esp/idf/components/hal /opt/esp/idf/components/heap /opt/esp/idf/components/idf_test /opt/esp/idf/components/jsmn /opt/esp/idf/components/json /opt/esp/idf/components/libsodium /opt/esp/idf/components/log /opt/esp/idf/components/lwip /root/Projects/moddable/build/tmp/esp32/m5stack/release/stackchan/xsProj-esp32/main /opt/esp/idf/components/mbedtls /opt/esp/idf/components/mdns /opt/esp/idf/components/mqtt /opt/esp/idf/components/newlib /opt/esp/idf/components/nghttp /opt/esp/idf/components/nvs_flash /opt/esp/idf/components/openssl /opt/esp/idf/components/partition_table /opt/esp/idf/components/perfmon /opt/esp/idf/components/protobuf-c /opt/esp/idf/components/protocomm /opt/esp/idf/components/pthread /opt/esp/idf/components/sdmmc /opt/esp/idf/components/soc /opt/esp/idf/components/spi_flash /opt/esp/idf/components/spiffs /opt/esp/idf/components/tcp_transport /opt/esp/idf/components/tcpip_adapter /opt/esp/idf/components/tinyusb /opt/esp/idf/components/ulp /opt/esp/idf/components/unity /opt/esp/idf/components/vfs /opt/esp/idf/components/wear_levelling /opt/esp/idf/components/wifi_provisioning /opt/esp/idf/components/wpa_supplicant /opt/esp/idf/components/xtensa
-- Configuring done
-- Generating done
CMake Warning:
  Manually-specified variables were not used by the project:

    CMAKE_MESSAGE_LOG_LEVEL

-- Build files have been written to: /root/Projects/moddable/build/tmp/esp32/m5stack/release/stackchan/xsProj-esp32/build
# cc xsAll.c (strings in flash)
# cc xsAPI.c (strings in flash)
# cc xsArguments.c (strings in flash)
# cc xsArray.c (strings in flash)
# cc xsAtomics.c (strings in flash)
# cc xsBigInt.c (strings in flash)
# cc xsBoolean.c (strings in flash)
# cc xsCode.c (strings in flash)
# cc xsCommon.c (strings in flash)
# cc xsDataView.c (strings in flash)
# cc xsDate.c (strings in flash)
# cc xsDebug.c (strings in flash)
# cc xsError.c (strings in flash)
# cc xsFunction.c (strings in flash)
# cc xsGenerator.c (strings in flash)
# cc xsGlobal.c (strings in flash)
# cc xsJSON.c (strings in flash)
# cc xsLexical.c (strings in flash)
# cc xsMapSet.c (strings in flash)
# cc xsMarshall.c (strings in flash)
# cc xsMath.c (strings in flash)
# cc xsMemory.c (strings in flash)
# cc xsModule.c (strings in flash)
# cc xsNumber.c (strings in flash)
# cc xsObject.c (strings in flash)
# cc xsPromise.c (strings in flash)
# cc xsProperty.c (strings in flash)
# cc xsProxy.c (strings in flash)
# cc xsRegExp.c (strings in flash)
# cc xsRun.c (strings in flash)
# cc xsScope.c (strings in flash)
# cc xsScript.c (strings in flash)
# cc xsSourceMap.c (strings in flash)
# cc xsString.c (strings in flash)
# cc xsSymbol.c (strings in flash)
# cc xsSyntaxical.c (strings in flash)
# cc xsTree.c (strings in flash)
# cc xsType.c (strings in flash)
# cc xsdtoa.c (strings in flash)
# cc xsre.c (strings in flash)
# cc xsmc.c (strings in flash)
# cc e_pow.c (strings in flash)
# cc xsPlatform.c (strings in flash)
/tmp/ccdvz4ds.s: Assembler messages:
/tmp/ccdvz4ds.s:260: Warning: setting incorrect section attributes for .rodata.mod.0
# cc xsHost.c (strings in flash)
# cc xsHosts.c (strings in flash)
# xsc pins/digital.xsb
# xsc ili9341.xsb
# xsc m5button.xsb
# xsc time.xsb
# xsc timer.xsb
# xsc Resource.xsb
# xsc mdns.xsb
# xsc dns.xsb
# xsc modules.xsb
# xsc wifi.xsb
# xsc socket.xsb
# xsc net.xsb
# xsc sntp.xsb
# xsc websocket.xsb
# xsc base64.xsb
# xsc logical.xsb
# xsc crypt.xsb
# xsc tts-remote.xsb
# xsc tts-local.xsb
# xsc http.xsb
# xsc commodetto/Bitmap.xsb
# xsc pins/digital/monitor.xsb
# xsc pins/audioout.xsb
# xsc setup/target.xsb
# xsc m5stack/screen.xsb
# xsc commodetto/Poco.xsb
# xsc commodetto/parseBMP.xsb
# xsc commodetto/parseRLE.xsb
# xsc piu/All.xsb
# xsc piu/Timeline.xsb
# xsc piu/CombTransition.xsb
# xsc piu/MC.xsb
# xsc piu/WipeTransition.xsb
# xsc setup/piu.xsb
# xsc dns/parser.xsb
# xsc dns/serializer.xsb
# xsc pins/servo.xsb
# xsc serial.xsb
# xsc init-network.xsb
# xsc speeches.xsb
# xsc mc/config.xsb
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
meganetaaan, 2022-02-07:
The [type definition of `Modules#importNow`](https://github.com/Moddable-OpenSource/moddable/commit/657f202f67ec8ea92b372d0c5c683fbfb0bb69fd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) causes this error.

thanks to @stc1988 for the report and hotfix: https://twitter.com/stc1988/status/1489079965651927045

The type is correct. I should treat them as `unknown`.

Closed 2022-02-07.

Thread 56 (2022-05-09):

possible issue pinning tilt angle in rs30x

phoddie, 2022-05-09:
I have recently had the pleasure of exploring the Stack-chan implementation by running it on the Stack-chan hardware! I don't know much about robotics, so I'm not sure about this issue.

I was exploring how to use the motors to have Stack-chan look side-to-side and up-and-down. Using the `yaw` to control side-to-side works well:

```js
robot._driver.applyPose({yaw: Math.PI / 3, pitch: 0});
robot._driver.applyPose({yaw: -Math.PI / 3, pitch: 0});
```

However, using the `pitch` to control up-and-down did not move the motors much, if at all.

```js
robot._driver.applyPose({yaw: 0, pitch: 0.43});
robot._driver.applyPose({yaw: 0, pitch: -0.17});
```

Eventually, I noticed this line in the RS30X driver:

https://github.com/meganetaaan/stack-chan/blob/168622e4905e027cdd6cc8e5e19553676ff59ba2/firmware/stackchan/rs30x-driver.ts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

This expression always evaluates to 10 in my tests. As an experiment, I changed it to the following:

```js
    let tiltAngle = -pose.pitch * 180 / Math.PI;
    if (tiltAngle < -25)
      tiltAngle = -25;
    else if (tiltAngle > 10)
      tiltAngle = 10;
```

I'm not sure whether I'm using the APIs incorrectly or if there is a mistake in the code that pins `tiltAngle`.

meganetaaan, 2022-05-10:
Hello @phoddie. Thank you for getting and exploring Stack-chan!
This was definitely a bug which I made in my latest commits.
Now I've fixed in https://github.com/meganetaaan/stack-chan/pull/57. Could you try it?

phoddie, 2022-05-10:
Thank you for the very quick response and fix! The change appears correct. Unfortunately, my Stack-chan is visiting San Jose for a few days, so I cannot try running the change for a little while.

phoddie, 2022-05-25:
Just to confirm, today I verified that the fix works as expected. Thanks again.

By the way, I noticed that I have a few changes to stackchan/manifest.json that might be useful. What is the best way to share that? For example, I can open an issue with some suggestions. Please let me know.

meganetaaan, 2022-07-17:
@phoddie
I'm happy to hear the fix works.

>By the way, I noticed that I have a few changes to stackchan/manifest.json that might be useful. What is the best way to share that? For example, I can open an issue with some suggestions. Please let me know.

Would you like to open an issue for your suggestions? Thank you!

Closed 2022-05-10.

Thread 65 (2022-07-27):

Making firmware environment setup more friendly

meganetaaan, 2022-07-27:
**Is your feature request related to a problem? Please describe.**

The setup steps for Moddable SDK are still tricky for beginners.
So we should help them to build the first Stack-chan application.

**Describe the solution you'd like**

Several solutions are considerable.

- Adding a description to README. Showing this situation makes surprises most negligible.
- Adopting environment setup tool like [`xs-dev`](https://www.npmjs.com/package/xs-dev). Building on the top of the docker container is more than tricky, especially for M1 Mac/Win(WSL).

phoddie, 2022-07-27:
@hipsterbrown has done great work in creating xs-dev:
- It automates the set-up and update of the Moddable SDK in the same way as the manual instructions.
- It starts from npm / node which makes it very easy for web developers to get started with.
- It is implemented in JavaScript (well, TypeScript 😉) which makes it easy for Moddable SDK developers to enhance.
- The Moddable team is actively supporting xs-dev development.

Beyond Moddable SDK set-up and updating, xs-dev has features in-progress to make it easy to create and manage new projects.

HipsterBrown, 2022-07-27:
Let me know if there's something should be added or fixed to make this more accessible for use in this project. 😃 I would love to test out the setup if I can find a M5 Stack available

meganetaaan, 2023-01-22:
I tried introducing xs-dev on the latest dev/v1.0 branch. I am using xs-dev to set up and diagnose the Moddable environment in the [project's npm script](https://github.com/meganetaaan/stack-chan/blob/dev/v1.0/firmware/package.json#L6). It works like a charm in my environment (Ubuntu 20.04)!
I did not use 'xs-dev run' because I did not know how to only run a specific phase of the build. I would be grateful if you could point out any issues in the project's settings.

phoddie, 2023-01-22:
@meganetaaan, thank you for trying out xs-dev. Great to hear that it is mostly working for you.

> ...I did not know how to only run a specific phase of the build...

You are referring to the [build targets](https://github.com/Moddable-OpenSource/moddable/blob/public/documentation/tools/tools.md#buildtargets) capability of `mcconfig`, such as `-t xsbug`? I think that should be straightforward to support, but we should hear from @HipsterBrown about the best way to do that.

shimodash, 2023-06-24:
I tried to install environment under Docker(24.0.2) on Ubuntu 20.04

I faced this error with npm run setup -- --device=esp32 command

```
> stack-chan@0.2.1 setup
> xs-dev setup --device=esp32

ℹ Ensuring esp32 install directory
✔ Cloning esp-idf repo
Reading package lists... Donees
Building dependency tree
Reading state information... Done
bison is already the newest version (2:3.5.1+dfsg-1).
ccache is already the newest version (3.7.7-1).
cmake is already the newest version (3.16.3-1ubuntu1.20.04.1).
dfu-util is already the newest version (0.9-1).
flex is already the newest version (2.6.4-6.2).
git is already the newest version (1:2.25.1-1ubuntu3.10).
gperf is already the newest version (3.1-1build1).
libffi-dev is already the newest version (3.3-4).
libssl-dev is already the newest version (1.1.1f-1ubuntu2.19).
ninja-build is already the newest version (1.10.0-1build1).
python-is-python3 is already the newest version (3.8.2-4).
python-setuptools is already the newest version (44.0.0-2ubuntu0.1).
python3-pip is already the newest version (20.0.2-5ubuntu1.8).
python3-serial is already the newest version (3.4-5.1).
wget is already the newest version (1.20.3-1ubuntu2).
⠙ Installing build dependencies0 upgraded, 0 newly installed, 0 to remove and 0 not upgraded.
✔ Installing build dependencies
⠋ Installing esp-idf toolingDetecting the Python interpreter
Checking "python" ...
Python 3.8.10
"python" has been detected
Installing ESP-IDF tools
⠙ Installing esp-idf toolingCurrent system platform: linux-amd64
⠹ Installing esp-idf tooling/workspace/node_modules/gluegun/build/index.js:15
    throw up;
    ^

Error: Command failed with exit code 1: ./install.sh
Traceback (most recent call last):
  File "/root/.local/share/esp32/esp-idf/tools/idf_tools.py", line 1860, in <module>
    main(sys.argv[1:])
  File "/root/.local/share/esp32/esp-idf/tools/idf_tools.py", line 1856, in main
    action_func(args)
  File "/root/.local/share/esp32/esp-idf/tools/idf_tools.py", line 1423, in action_install
    targets = clean_targets(args.targets)
  File "/root/.local/share/esp32/esp-idf/tools/idf_tools.py", line 1085, in clean_targets
    export_targets_to_idf_env_json(targets_from_tools_json)
  File "/root/.local/share/esp32/esp-idf/tools/idf_tools.py", line 1053, in export_targets_to_idf_env_json
    targets = list(set(targets + get_user_defined_targets()))
  File "/root/.local/share/esp32/esp-idf/tools/idf_tools.py", line 1099, in get_user_defined_targets
    if env == idf_env_json['idfSelectedId']:
KeyError: 'idfSelectedId'
    at makeError (/workspace/node_modules/execa/lib/error.js:60:11)
    at handlePromise (/workspace/node_modules/execa/index.js:118:26)
    at process.processTicksAndRejections (node:internal/process/task_queues:95:5) {
  shortMessage: 'Command failed with exit code 1: ./install.sh',
  command: './install.sh',
  escapedCommand: '"./install.sh"',
  exitCode: 1,
  signal: undefined,
  signalDescription: undefined,
  stdout: undefined,
  stderr: 'Traceback (most recent call last):\n' +
    '  File "/root/.local/share/esp32/esp-idf/tools/idf_tools.py", line 1860, in <module>\n' +
    '    main(sys.argv[1:])\n' +
    '  File "/root/.local/share/esp32/esp-idf/tools/idf_tools.py", line 1856, in main\n' +
    '    action_func(args)\n' +
    '  File "/root/.local/share/esp32/esp-idf/tools/idf_tools.py", line 1423, in action_install\n' +
    '    targets = clean_targets(args.targets)\n' +
    '  File "/root/.local/share/esp32/esp-idf/tools/idf_tools.py", line 1085, in clean_targets\n' +
    '    export_targets_to_idf_env_json(targets_from_tools_json)\n' +
    '  File "/root/.local/share/esp32/esp-idf/tools/idf_tools.py", line 1053, in export_targets_to_idf_env_json\n' +
    '    targets = list(set(targets + get_user_defined_targets()))\n' +
    '  File "/root/.local/share/esp32/esp-idf/tools/idf_tools.py", line 1099, in get_user_defined_targets\n' +
    "    if env == idf_env_json['idfSelectedId']:\n" +
    "KeyError: 'idfSelectedId'",
  failed: true,
  timedOut: false,
  isCanceled: false,
  killed: false
}

Node.js v18.16.1

```
Could you please tell me how to fix this error?

phoddie, 2023-06-25:
@HipsterBrown - any advice?

HipsterBrown, 2023-06-27:
I'll need to try running through this myself. The error output from the esp-idf isn't providing a lot of context.

I should probably start setting up some E2E testing for the setup scenarios to make sure they continue to work across OS and device options.

HipsterBrown, 2023-06-27:
I believe I discovered the issue.

The Docker image used by the `firmware/docker/Dockerfile` contains a version (v4.4.3) of the `idf-env.json` at the IDF_TOOLS_PATH that the esp-idf install script uses to determine the installed environment devices. The version of the esp-idf pulled in by xs-dev is different (v4.4.2), so the install script throws an error when it doesn't find an expected key. https://github.com/espressif/esp-idf/issues/9837

This can be fixed in xs-dev by updating the esp-idf tagged version to v4.4.3, which will then require the stack-chan firmware to update its xs-dev dependency version to that released fix version (probably v0.25.13).

While working on this, I noticed the published Docker image from the `docker-moddable-esp32` project sets up the Moddable tooling itself from the public branch at the time of building the image: https://github.com/meganetaaan/docker-moddable-esp32/blob/master/Dockerfile.head#L32-L36
This could become tricky to coordinate with xs-dev, which attempts to use the latest tagged releases of Moddable. So I would probably document that `npm run setup` is not required (I believe) or recommended when using the Docker environment.

Official xs-dev Docker images is on the list of [proposed integrations](https://github.com/HipsterBrown/xs-dev/discussions/131) to make this a more seamless experience.

shimodash, 2023-07-01:
@HipsterBrown thank you for comment.
How I check esp-idf version under docker envrionment...
I user fix version(0.25.13)
attached Dockerfile
[Dockerfile.txt](https://github.com/meganetaaan/stack-chan/files/11927645/Dockerfile.txt)

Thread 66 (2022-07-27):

suggested improvements to manifest.json

phoddie, 2022-07-27:
I would like to suggest a few small improvements to [firmware/stackchan/manifest.json](https://github.com/meganetaaan/stack-chan/blob/main/firmware/stackchan/manifest.json).

1. For the HTTP module, use the manifest provided by the Moddable SDK. Simply add `$(MODDABLE)/modules/network/http/manifest.json` to the `include` section and remove http from the `modules` and `preload` sections. This will keep Stackchan in-sync with future changes to HTTP.
2. Add `button` and `sg90-driver` to the `preload` section. This saves memory.
3. Increase `creation/keys` from 128 to 512. This is the number of unique property names a mod can contain. In my experiments, 128 was not enough. Each key in this table uses 4 bytes, so this uses an additional 1.5 KB. The ESP32 has lots of free memory running Stackchan, so this shouldn't be a problem.

Additionally, the M5Stack Core 2 port now [implements support for the touch buttons](https://github.com/Moddable-OpenSource/moddable/commit/3223338b8f0dc6e96295f426e36630dff977ba3d). I think this means that you may be able to remove the `button` module and the [code to set-up the pseudo-buttons](https://github.com/meganetaaan/stack-chan/blob/0c52a56b08896ac949b15ca048b5c2cfa1c15af1/firmware/stackchan/main.ts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) from main.ts.

Thank you for considering these suggestions.

meganetaaan, 2023-10-23:
Very late reply but these are now all resolved in the latest [`manifest.json`](https://github.com/meganetaaan/stack-chan/blob/dev/v1.0/firmware/stackchan/manifest.json) .
In addition, for reusability, [I separated the manifest file into modules](https://github.com/meganetaaan/stack-chan/pull/202).

Thank you for your suggestion!

phoddie, 2023-10-23:
Thank you. Just one FYI.

> Increase creation/keys from 128 to 512

This was the best practice when this issue was opened. Since that time, XS has been enhanced to automatically grow the keys array when necessary. Therefore, it is no longer necessary to preallocate the worst-case number of keys.

It is probably a good idea to keep this change in place because it will be a little faster than growing the key array and may reduce memory fragmentation.  The incremental amount of memory is 1.5 KB (4 bytes for each reserved key entry) which is probably not an issue on the devices that typically host Stack-chan.

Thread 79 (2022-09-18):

NL27WZ125 is discontinued

meganetaaan, 2022-09-18:
**Describe the bug**
NL27WZ125 is discontinued. We should find an alternative.

https://www.digikey.jp/ja/products/detail/onsemi/NL27WZ125USG/661486

washishi, 2022-10-01:
TC7WH241FK もメーカーページで出てこない様なのでディスコンかも

TC7WH125FK が使えそう
https://toshiba.semicon-storage.com/jp/semiconductor/product/general-purpose-logic-ics/detail.TC7WH125FK.html

鈴商で扱っているよう(10個セット200円 + 送料・・・)
https://suzushoweb.shop-pro.jp/?pid=101173315
鈴商 昔は秋葉に店舗あったんだけどなぁ・・・

meganetaaan, 2023-10-23:
新基板では3ステートバッファの代わりにRS485のICを採用したため、こちらの問題は解消されました。

---

In the new circuit board, we replaced the 3-state buffer with an RS485 IC, resolving the issue.

Closed 2023-10-23.

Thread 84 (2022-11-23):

Battery backpack 640mah interferes with SG-90 case

meganetaaan, 2022-11-23:
https://twitter.com/plus9y/status/1595313990678482944

meganetaaan, 2023-10-23:
Fixed in #207

Closed 2023-10-23.

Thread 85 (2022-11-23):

Add software implementation guide/ ソフトウェアの実装ガイドを追加する

meganetaaan, 2022-11-23:
**Is your feature request related to a problem? Please describe.**

Stack-chan's firmware is built on a number of platforms and middleware

- npm
- Moddable SDK
- Stack-chan modules (text-to-speech, servo motor driver, face renderer, and more)

There is no document about how to build and flash the firmware.

---

ｽﾀｯｸﾁｬﾝのソフトウェアは様々なプラットフォームやミドルウェアを使ってビルドされます。

- npm
- Moddable SDK
- ｽﾀｯｸﾁｬﾝのモジュール（音声合成、サーボモータのドライバ、顔の描画など）

ファームウェアをビルドして書き込む方法の説明資料がまだありません。

**Describe the solution you'd like**

Add software guidelines. For example:

- First steps
- Writing mod
- Customizing face
- Text to speech
- BLE
- API

---

ソフトウェア実装のガイドラインを追加します。例えば次のようなものです。

- 最初のステップ
- modを書く
- 顔のカスタマイズ
- 音声合成
- BLEについて
- APIの説明

meganetaaan, 2023-01-04:
This includes https://github.com/meganetaaan/stack-chan/issues/44 and https://github.com/meganetaaan/stack-chan/issues/35

meganetaaan, 2023-01-10:
Working on https://github.com/meganetaaan/stack-chan/tree/feature/docs branch.

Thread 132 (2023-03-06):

Integrate ChatGPT

meganetaaan, 2023-03-06:
The time has come! As soon as ChatGPT's API was opened, one of Stack-chan's users demonstrated a demonstration of integrating ChatGPT with Stack-chan.

https://twitter.com/robo8080/status/1631224076005179393?s=20

Mr. robo8080 created it using Arduino stacks such as M5Stack-Avatar.
"A robot that can talk to users" is the destiny of Stack-chan, and we would like to achieve this in our repository as well.

First, it is good to start with providing a thin wrapper for the ChatGPT Web API, followed by implementing a DialogManager.

The following functions are probably already present in existing dialogue systems and are desirable to implement:

- Easily set the context (system message in ChatGPT)
- Context presets to output extended syntax to change the generation method and facial expressions of Stack-chan
- Manage the user's and assistant's speech history
- Switch multiple contexts according to rules.

meganetaaan, 2023-04-18:
Introduction of ChatGPT demo on Hackaday
https://hackaday.io/project/181344-stack-chan-javascript-driven-super-kawaii-robot/log/217588-chatgpt-x-stack-chan-act2

stc1988, 2024-08-24:
We have implemented integration with several AI assistant services, including ChatGPT. If there are any remaining tasks, can we close this issue by creating a separate issue for them?

meganetaaan, 2024-10-06:
The following features have already been implemented:

- Easily setting the context (system message in ChatGPT)
- Managing the conversation history between the user and assistant

The following features could be implemented using Function Calling, as discussed in [Stack-chan Issue #293](https://github.com/stack-chan/stack-chan/issues/293):

- Context presets that output extended syntax for changing Stack-chan’s generation methods and facial expressions
- Switching between multiple contexts based on specific rules

Closed 2024-10-06.

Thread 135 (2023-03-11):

M5Stack Core2がエラーと再起動を繰り返す

meganetaaan, 2023-03-11:
**不具合の概要**

M5Stack Core2がエラーと再起動を繰り返す。

https://twitter.com/tomolld/status/1634547949618495488

**再現手順**
不具合を再現できる手順を記述してください
1. `npm run debug --target=esp32/m5stack_core2`を実行
2. 下記エラーが発生する

**ログ**

xsbugのログ

```log
No Wi-Fi SSID
/root/Projects/moddable/modules/drivers/ft6206/modFt6206.c (131) # Break: FT6202: bad FT6206_REG_VENDID!
```

**環境 (次の項目を埋めてください):**

- OS: [Windows, MacOS, Linux(Ubuntu/Arch/etc.)] Docker
- IDE: [Arduino IDE, VSCode, UIFlow]
- ｽﾀｯｸﾁｬﾝのバージョン M5Bottom版キット
- 使用するM5Stackの種類 M5Stack Core2

meganetaaan, 2023-03-13:
手元の環境で試したが、再現せず。

- Ubuntu
- cfc19242e6b13ebfa2ce1858bb9f5e96d1bc0c2d（`dev/v1.0`の最新コミット）
- M5Stack Core2

Fuji-P, 2023-03-14:
すみません。同様の現象が発生したため書き込ませていただきます。

不具合の概要

M5Stack Core2がエラーと再起動を繰り返す（画面が黒いまま振動を続けた状態）。

再現手順
不具合を再現できる手順を記述してください
ビルド手順は下記リンクを参考にした
https://zenn.dev/yh1224/articles/34f8383gea793f1gf

package.jsonは下記を設定
{
    "config": {
        "driver": {
            "type": "pwm",
            "pwmPan": 13,
            "pwmTilt": 14
        }
    }
}

npm run debug --target=esp32/m5stack_core2を実行
xsbugのログ
→ログが出力されませんでした。Macだから？

OS：MacOS Ventura 13.2.1（M1）MacBook Air　
IDE：CLI（ModdableSDK）
ｽﾀｯｸﾁｬﾝのバージョン：M5Bottom版キット
使用するM5Stackの種類：M5Stack Core2

Fuji-P, 2023-03-15:
こちらの[リンク](https://twitter.com/lovyan03/status/1635876865113231361?s=20)のコメントみて
`if ((1 != data[0]) && (17 != data[0])) xsUnknownError("bad FT6206_REG_VENDID");`
に変更したところ、上記の環境で無事起動することができました。
取り急ぎ報告まで

meganetaaan, 2023-03-16:
@Fuji-P
報告ありがとうございます！これはModdable側の修正が必要ですね。
取り急ぎModdableのリポジトリにissueを立てました。https://github.com/Moddable-OpenSource/moddable/issues/1064
差し支えなければ上記の変更を、Moddable本家にプルリクエスト出してみませんか？

Fuji-P, 2023-03-16:
@meganetaaan
issueの件ご対応いただきありがとうございます。
プルリクエストの件、間に合うようなら夜くらいに対応したいと思います。

stc1988, 2023-03-16:
@meganetaaan
コードは問題無いかと思いますが、issueのほうで関連するデータシートがあるか聞かれているようなので困りましたね😅

meganetaaan, 2023-03-16:
https://github.com/Moddable-OpenSource/moddable/issues/1064#issuecomment-1471367216
データシートの件補足しました。ドキュメント上は今も昔もFT6336Uを使っているらしい。

Fuji-P, 2023-03-16:
@meganetaaan
色々補足いただきありがとうございます。
下記PRを出してみました。
https://github.com/Moddable-OpenSource/moddable/pull/1065

stc1988, 2023-03-18:
PRがマージされました。
私のModdableSDK環境を更新して、旧型のCore2の方でも問題なく動きました。

meganetaaan, 2023-03-22:
問題が解消されたためクローズします。

今後もM5Stack側のチップが新しくなる等で事象が再発する可能性があります。その際はReopenしてください。

Closed 2023-03-22.

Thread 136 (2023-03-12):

Windows環境でnpm run buildが失敗する

stc1988, 2023-03-12:
**不具合の概要**
Windows環境において`npm run build` を実施すると以下エラーが発生します。

```
C:\Users\satt6\Projects\stack-chan\firmware>npm run build

> stack-chan@0.2.1 build
> cross-var mcconfig -d -m -p ${npm_config_target=esp32/m5stack} -t build ./stackchan/manifest.json

### Error: '$(BLEMODULEPATH)/modBLEServer': directory not found!
npm ERR! code 1
npm ERR! path C:\Users\satt6\Projects\stack-chan\firmware
npm ERR! command failed
npm ERR! command C:\WINDOWS\system32\cmd.exe /d /s /c cross-var mcconfig -d -m -p ${npm_config_target=esp32/m5stack} -t build ./stackchan/manifest.json

npm ERR! A complete log of this run can be found in:
npm ERR!     C:\Users\satt6\AppData\Local\npm-cache\_logs\2023-03-12T13_27_52_386Z-debug.log
```
**環境 (次の項目を埋めてください):**

- OS: Windows
- ｽﾀｯｸﾁｬﾝのバージョン: https://github.com/meganetaaan/stack-chan/commit/cfc19242e6b13ebfa2ce1858bb9f5e96d1bc0c2d
- 使用するM5Stackの種類: M5stack

**その他**

[package.json](https://github.com/meganetaaan/stack-chan/blob/dev/v1.0/firmware/package.json#L15) でターゲットデバイスを指定するために`${npm_config_target=esp32/m5stack}` という記載がありますが、Windowsではこの記法が使えないようです。`%`で囲う必要があります。

[cross-var](https://www.npmjs.com/package/cross-var)や[cross-conf-env](https://www.npmjs.com/package/cross-conf-env) といったパッケージを導入するとLinux/macとも統一した記載ができますが、`--target`省略時の初期値を設定する方法は分かっていません。

初期値を設定する方法がなければ、`esp32/m5stack`の場合でも明示的に指定することで解決はできます。

stc1988, 2023-03-12:
ソフトウェアの修正無しに動かすためには、`package.json`のscirptを参考に`mcconfig -d -m -p esp32/m5stack -t build stackchan\manifest.json` と直接`mcconfig`コマンドを実行することで回避できます。

washishi, 2023-03-18:
cross-env-default というのがある様です
  https://www.npmjs.com/package/cross-env-default
こちらは cross-env [環境変数名]?=[未定義の際のデフォルト値]  という書き方ができるので
それと cross-var を組み合わせて下記のように記述すればとりあえず環境依存は無くせそうです
cross-env npm_config_target?=esp32/m5stack cross-var mcconfig -d -m -p $npm_config_target -t build ./stackchan/manifest.json
もっと簡単な方法があるかもしれませんが

stc1988, 2023-03-21:
twitterの方で情報をいただいた[cross-env](https://www.npmjs.com/package/@naholyr/cross-env)の方であれば、このパッケージ単独でmacは解決はできました。

washishi, 2023-03-24:
修正完了したのプルリク送りました
  https://github.com/meganetaaan/stack-chan/pull/149
色々試しましたが結局最初の cross-env-default モジュールのみで対応しました
またついでに generate-speech-google の env も cross-env への変更と
keyファイルのパスをscriptsディレクトリに変更しています

washishi, 2023-03-24:
あ・・Isuue番号間違えてる・・・一転取り消して再度送ります

washishi, 2023-03-24:
すいません送りなおしました
https://github.com/meganetaaan/stack-chan/pull/150

stc1988, 2023-03-25:
対応ありがとうございます。macても見てみますね

stc1988, 2023-03-25:
macでもbuildおよびpostbuildが引数なし（デフォルト値および）とesp32/m5stack_core2両方でエラー無く動作することを確認しました。

washishi, 2023-03-25:
package.jsonの依存は無くなったのですがWindowsでxs-dev使って確実にビルドできる方法が見つからずまだ試行錯誤中・・・

stc1988, 2023-03-25:
私の方でもwindows環境で確認可能なので、事象共有いただければ見ることできます

meganetaaan, 2023-03-27:
私のLinux（Ubuntu 20.04）環境でもビルドできました。ありがとうございます！PRを取り込みました。

xs-devのWindowsサポートは[まだベータ版なんですね](https://hipsterbrown.github.io/xs-dev/en/introduction/)。
ドキュメントに追記したほうがいいかも。

washishi, 2023-03-27:
ｽﾀｯｸﾁｬﾝファームウエアビルド時のエラーは下記[666/1144]で始まるところからです
証明書の処理のところでpythonのモジュールでエラーになってます
最初モジュールがないのか？と思いましたがモジュールはある様
手動ではESP-IDF 4.4.2でも正常にビルドできました
　(Recommend using ESP-IDF v4.4.3 (found v4.4.2) って出るけど)
Merged 1 ELF section
Successfully created esp32 image.
Generated C:/Users/stackchan/xs-dev/moddable/build/tmp/esp32/m5stack/debug/stackchan/xsProj-esp32/build/bootloader/bootloader.bin
[97/97] cmd.exe /C "cd /D C:\Users\stackchan\xs-dev\moddable\build\tmp\esp32\m5stack\debug\stackchan\xsProj-esp32\build\bootloader\esp-idf\esptool_py && C:\Espressif\python_env\idf4.4_py3.8_env\Scripts\python.exe C:/Users/stackchan/xs-dev/esp32/esp-idf/components/partition_table/check_sizes.py --offset 0x8000 bootloader 0x1000 C:/Users/stackchan/xs-dev/moddable/build/tmp/esp32/m5stack/debug/stackchan/xsProj-esp32/build/bootloader/bootloader.bin"
Bootloader binary size 0x4470 bytes. 0x2b90 bytes (39%) free.
[666/1144] Generating x509_crt_bundle
FAILED: esp-idf/mbedtls/x509_crt_bundle C:/Users/stackchan/xs-dev/moddable/build/tmp/esp32/m5stack/debug/stackchan/xsProj-esp32/build/esp-idf/mbedtls/x509_crt_bundle
cmd.exe /C "cd /D C:\Users\stackchan\xs-dev\moddable\build\tmp\esp32\m5stack\debug\stackchan\xsProj-esp32\build\esp-idf\mbedtls && C:\Espressif\python_env\idf4.4_py3.8_env\Scripts\python.exe C:/Users/stackchan/xs-dev/esp32/esp-idf/components/mbedtls/esp_crt_bundle/gen_crt_bundle.py --input C:/Users/stackchan/xs-dev/esp32/esp-idf/components/mbedtls/esp_crt_bundle/cacrt_all.pem C:/Users/stackchan/xs-dev/esp32/esp-idf/components/mbedtls/esp_crt_bundle/cacrt_local.pem -q"
The cryptography package is not installed.Please refer to the Get Started section of the ESP-IDF Programming Guide for setting up the required packages.
Traceback (most recent call last):
  File "C:/Users/stackchan/xs-dev/esp32/esp-idf/components/mbedtls/esp_crt_bundle/gen_crt_bundle.py", line 36, in <module>
    from cryptography import x509
  File "C:\Espressif\python_env\idf4.4_py3.8_env\lib\site-packages\cryptography\x509\__init__.py", line 6, in <module>
    from cryptography.x509 import certificate_transparency
  File "C:\Espressif\python_env\idf4.4_py3.8_env\lib\site-packages\cryptography\x509\certificate_transparency.py", line 10, in <module>
    from cryptography.hazmat.bindings._rust import x509 as rust_x509
ImportError: DLL load failed while importing _rust: %1 は有効な Win32 アプリケーションではありません。
ninja: build stopped: subcommand failed.
ninja failed with exit code 1
NMAKE : fatal error U1077: 'python %IDF_PATH%\tools\idf.py -n build -D mxDebug=1 -D INSTRUMENT=1 -D TMP_DIR="C:\Users\stackchan\xs-dev\moddable\build\tmp\esp32\m5stack\debug\stackchan" -D SDKCONFIG_HEADER="C:\Users\stackchan\xs-dev\moddable\build\tmp\esp32\m5stack\debug\stackchan\xsProj-esp32\build\config\sdkconfig.h" -D CMAKE_MESSAGE_LOG_LEVEL=ERROR -D DEBUGGER_SPEED=460800 -D ESP32_SUBCLASS=esp32' : リターン コード '0x2'

stc1988, 2023-03-28:
```
手動ではESP-IDF 4.4.2でも正常にビルドできました
　(Recommend using ESP-IDF v4.4.3 (found v4.4.2) って出るけど)
```

私の方ではESP-IDF v4.4.4ですが、`npm run build` は成功していました。
手動というのはnpm scriptではなく、`mcconfig`を直接実行した理解でよろしいでしょうか。

washishi, 2023-04-01:
証明書の処理のところでpythonのモジュールでエラーになる件
Pythonの違いが関係してるようです
環境構築にxs-devを使うとidf-installer2.15が動いてPython 3.8.7を取得しそれが常に使われる
手動で環境構築した場合は別途インストールしているPython3.10が使われる

stc1988, 2023-04-01:
別事象ですが、私も最近macでpython3の新しいのを入れるとビルドにこけました。

事象としては、stack-chanとも関係が無くなってきたので、一旦本issueはクローズしますね

Closed 2023-04-01.

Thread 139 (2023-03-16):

M5StackCore2にファームウェアを入れるとスタックチャンの顔が表示されるが何も動かない

Fuji-P, 2023-03-16:
**不具合の概要**
ファームウェアを入れるとスタックチャンの顔が表示されるが何も動かない

**再現手順**
Core2にファームウェアを導入

**想定する挙動**
「ランダムに動く」が正だと思われる
https://twitter.com/fuji_producer/status/1636011112587214848?s=20

**ログ**
なし

**スクリーンショット**
https://twitter.com/fuji_producer/status/1635994410079879170?s=20

**環境:**
OS：MacOS Ventura 13.2.1（M1）MacBook Air　
IDE：CLI（ModdableSDK）
ｽﾀｯｸﾁｬﾝのバージョン：M5Bottom版キット
使用するM5Stackの種類：M5Stack Core2（3/5頃購入）

**その他**
[設定例: ｽﾀｯｸﾁｬﾝ M5Bottom版キットを動かす](https://github.com/meganetaaan/stack-chan/blob/dev/v1.0/firmware/docs/flashing-firmware_ja.md)と[ｽﾀｯｸﾁｬﾝ で始める M5Stack](https://zenn.dev/yh1224/articles/34f8383gea793f1gf)の記述で気になったのですが、
サーボの設定はstack-chan/firmware/stackchan/manifest.jsonに記載するのか、stack-chan/firmware/stackchan/manifest_local.jsonに書き込むのかがわかりませんでした。

manifest.jsonの
```
    "platforms": {
        "esp32/m5stack_core2": {
            "include": ["./manifest_8mb_flash.json"],
            "config": {
                "driver": {
                    "pwmPan": 19,
                    "pwmTilt": 27
                },

```
を
```
    "platforms": {
        "esp32/m5stack_core2": {
            "include": ["./manifest_8mb_flash.json"],
            "config": {
                "driver": {
                    "type": "pwm",
                    "pwmPan": 19,
                    "pwmTilt": 27
                },

```
とするのか

manifest_local.jsonの
```
        "driver": {
            "type": "scservo",
            "panId": 1,
            "tiltId": 2,
            "offsetTilt": 0,
            "offsetPan": 0
        }

```
を
```
        "driver": {
            "type": "pwm",
            "pwmPan": 13,
            "pwmTilt": 14
        }

```
とするのか

meganetaaan, 2023-03-17:
報告ありがとうございます。
確認したところ、ドキュメントの記載やマニフェストファイルに2点ミスがありました。

**①manifest.jsonの値が（意図せず）優先されている**

[公式ドキュメント](https://github.com/meganetaaan/stack-chan/blob/dev/v1.0/firmware/docs/flashing-firmware_ja.md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)では`manifest_local.json`の値を変えるように指示していますが、
現状では`manifest_local.json`に記載した`pwmPan`や`pwmTilt`の設定が`manifest.json`の値で上書きされてしまいます。

回避策として`manifest.json`の値を書き換えると反映されます。

**②設定例が`Port.C`のピン番号になっている**

```
                    "pwmPan": 19,
                    "pwmTilt": 27
```

このピン番号はM5Stack Core2の`Port.C`を使う場合の設定例でした。
スクリーンショットのように`Port.A`（M5Stack Core2本体側面の赤い穴）を使う場合は下記のピン番号になります。

```
                    "pwmPan": 32,
                    "pwmTilt": 33
```
（つなぎ方によってはPanとTiltが逆になるかもです）

参考：https://raspberrypi.mongonta.com/softwares-for-stackchan/

---

まとめると、`manifest.json`の該当箇所を以下のようにすると動作すると思われます。
試してみていただけますか？

```
    "platforms": {
        "esp32/m5stack_core2": {
            "include": ["./manifest_8mb_flash.json"],
            "config": {
                "driver": {
                    "type": "pwm",
                    "pwmPan": 32,
                    "pwmTilt": 33
                },
```

Fuji-P, 2023-03-17:
上記に関して動作確認しました。
```
    "platforms": {
        "esp32/m5stack_core2": {
            "include": ["./manifest_8mb_flash.json"],
            "config": {
                "driver": {
                    "type": "pwm",
                    "pwmPan": 32,
                    "pwmTilt": 33
                },
```
→こちらでは上下の首振り

```
    "platforms": {
        "esp32/m5stack_core2": {
            "include": ["./manifest_8mb_flash.json"],
            "config": {
                "driver": {
                    "type": "pwm",
                    "pwmPan": 33,
                    "pwmTilt": 32
                },

```
→こちらでは左右の首振りとなります。
どちらが想定される動作でしょうか？

meganetaaan, 2023-03-23:
**①manifest.jsonの値が（意図せず）優先されている**

解決策として`manifest_local.json`から`manifest.json`をincludeするようにしました。（ https://github.com/meganetaaan/stack-chan/commit/8e9da3352883e4c58e3db2a726fb8ae39ba6a17e ）。こうすることで`manifest_local.json`の設定が最も優先されるようになります。

Closed 2023-03-21.

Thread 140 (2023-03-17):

Mac devContainer環境でビルドがうまくいかない

DaisukeMiyazaki, 2023-03-17:
**不具合の概要**
Mac devContainer環境でビルドがうまくいかない

**再現手順**
1. '/firmware '下でvscodeからソースコードを開く。dev containerで開きますかと聞かれるのではい -> remote desktopコンテナ内でVScodeが開く
2. root@docker-desktop:/workspaces/stack-chan/firmware# で npm install 後, m5stack core2のみ(他パーツなし)をUSB接続し、/stackchan/firmware/ 以下で `npm run build --target=esp32/m5stack_core2` を走らせる
3. ''./scservo/src/manifest-driver.json': manifest not found!'というエラーが発生する

**想定する挙動**
Buildが通り /build 以下ディレクトリに配置される

**ログ**
```
root@docker-desktop:/workspaces/stack-chan/firmware# npm run build  --target=esp32/m5stack_core2

> stack-chan@0.2.1 build /workspaces/stack-chan/firmware
> mcconfig -d -m -p ${npm_config_target=esp32/m5stack} -t build ./stackchan/manifest.json

### Error: './scservo/src/manifest-driver.json': manifest not found!
npm ERR! code ELIFECYCLE
npm ERR! errno 1
npm ERR! stack-chan@0.2.1 build: `mcconfig -d -m -p ${npm_config_target=esp32/m5stack} -t build ./stackchan/manifest.json`
npm ERR! Exit status 1
npm ERR!
npm ERR! Failed at the stack-chan@0.2.1 build script.
npm ERR! This is probably not a problem with npm. There is likely additional logging output above.

npm ERR! A complete log of this run can be found in:
npm ERR!     /root/.npm/_logs/2023-03-17T07_08_19_669Z-debug.log

```
```
0 info it worked if it ends with ok
1 verbose cli [
1 verbose cli   '/usr/bin/node',
1 verbose cli   '/usr/bin/npm',
1 verbose cli   'run',
1 verbose cli   'build',
1 verbose cli   '--target=esp32/m5stack_core2'
1 verbose cli ]
2 info using npm@6.14.18
3 info using node@v14.21.3
4 verbose run-script [ 'prebuild', 'build', 'postbuild' ]
5 info lifecycle stack-chan@0.2.1~prebuild: stack-chan@0.2.1
6 info lifecycle stack-chan@0.2.1~build: stack-chan@0.2.1
7 verbose lifecycle stack-chan@0.2.1~build: unsafe-perm in lifecycle true
8 verbose lifecycle stack-chan@0.2.1~build: PATH: /usr/lib/node_modules/npm/node_modules/npm-lifecycle/node-gyp-bin:/workspaces/stack-chan/firmware/node_modules/.bin:/opt/esp/idf/components/esptool_py/esptool:/opt/esp/idf/components/espcoredump:/opt/esp/idf/components/partition_table:/opt/esp/idf/components/app_update:/vscode/vscode-server/bin/linux-x64/5e805b79fcb6ba4c2d23712967df89a089da575b/bin/remote-cli:/opt/esp/idf/components/esptool_py/esptool:/opt/esp/idf/components/espcoredump:/opt/esp/idf/components/partition_table:/opt/esp/idf/components/app_update:/opt/esp/tools/xtensa-esp32-elf/esp-2021r2-patch5-8.4.0/xtensa-esp32-elf/bin:/opt/esp/tools/xtensa-esp32s2-elf/esp-2021r2-patch5-8.4.0/xtensa-esp32s2-elf/bin:/opt/esp/tools/xtensa-esp32s3-elf/esp-2021r2-patch5-8.4.0/xtensa-esp32s3-elf/bin:/opt/esp/tools/riscv32-esp-elf/esp-2021r2-patch5-8.4.0/riscv32-esp-elf/bin:/opt/esp/tools/esp32ulp-elf/2.35_20220830/esp32ulp-elf/bin:/opt/esp/tools/cmake/3.23.1/bin:/opt/esp/tools/openocd-esp32/v0.11.0-esp32-20220706/openocd-esp32/bin:/opt/esp/python_env/idf4.4_py3.8_env/bin:/opt/esp/idf/tools:/usr/local/sbin:/usr/local/bin:/usr/sbin:/usr/bin:/sbin:/bin:/root/Projects/moddable/build/bin/lin/release
9 verbose lifecycle stack-chan@0.2.1~build: CWD: /workspaces/stack-chan/firmware
10 silly lifecycle stack-chan@0.2.1~build: Args: [
10 silly lifecycle   '-c',
10 silly lifecycle   'mcconfig -d -m -p ${npm_config_target=esp32/m5stack} -t build ./stackchan/manifest.json'
10 silly lifecycle ]
11 silly lifecycle stack-chan@0.2.1~build: Returned: code: 1  signal: null
12 info lifecycle stack-chan@0.2.1~build: Failed to exec build script
13 verbose stack Error: stack-chan@0.2.1 build: `mcconfig -d -m -p ${npm_config_target=esp32/m5stack} -t build ./stackchan/manifest.json`
13 verbose stack Exit status 1
13 verbose stack     at EventEmitter.<anonymous> (/usr/lib/node_modules/npm/node_modules/npm-lifecycle/index.js:332:16)
13 verbose stack     at EventEmitter.emit (events.js:400:28)
13 verbose stack     at ChildProcess.<anonymous> (/usr/lib/node_modules/npm/node_modules/npm-lifecycle/lib/spawn.js:55:14)
13 verbose stack     at ChildProcess.emit (events.js:400:28)
13 verbose stack     at maybeClose (internal/child_process.js:1088:16)
13 verbose stack     at Process.ChildProcess._handle.onexit (internal/child_process.js:296:5)
14 verbose pkgid stack-chan@0.2.1
15 verbose cwd /workspaces/stack-chan/firmware
16 verbose Linux 5.10.124-linuxkit
17 verbose argv "/usr/bin/node" "/usr/bin/npm" "run" "build" "--target=esp32/m5stack_core2"
18 verbose node v14.21.3
19 verbose npm  v6.14.18
20 error code ELIFECYCLE
21 error errno 1
22 error stack-chan@0.2.1 build: `mcconfig -d -m -p ${npm_config_target=esp32/m5stack} -t build ./stackchan/manifest.json`
22 error Exit status 1
23 error Failed at the stack-chan@0.2.1 build script.
23 error This is probably not a problem with npm. There is likely additional logging output above.
24 verbose exit [ 1, true ]
```

**環境**

- OS: [MacOS]
- IDE: [VSCode]
- MacbookAir M1chip
- 使用するM5Stackの種類:Core2
-  dev/1.0 latest

**その他**
1. extern/manifest_extern.jsonからエラーとみられる行をコメントアウトするとビルドは完了するが、他のエラーがでる
```
./scservo/src/manifest-driver.json",
      "./rs30x/src/manifest-driver.json"
```

```
drivers/rs30x-driver.ts:1:19 - error TS2792: Cannot find module 'rs30x'. Did you mean to set the 'moduleResolution' option to 'node', or to add aliases to the 'paths' option?

1 import RS30X from 'rs30x'
                    ~~~~~~~

drivers/scservo-driver.ts:1:21 - error TS2792: Cannot find module 'scservo'. Did you mean to set the 'moduleResolution' option to 'node', or to add aliases to the 'paths' option?

1 import SCServo from 'scservo'
                      ~~~~~~~~~

Found 2 errors in 2 files.

Errors  Files
     1  drivers/rs30x-driver.ts:1
     1  drivers/scservo-driver.ts:1
make: *** [/root/Projects/moddable/build/tmp/esp32/m5stack_core2/debug/stackchan/makefile:1733: /root/Projects/moddable/build/tmp/esp32/m5stack_core2/debug/stackchan/modules/workspaces/stack-chan/firmware/stackchan/ble/beacon-packet.js] Error 2
make: *** Waiting for unfinished jobs....
Loading defaults file /root/Projects/moddable/build/tmp/esp32/m5stack_core2/debug/stackchan/xsProj-esp32/sdkconfig.mc...
/tmp/confgen_tmpp22cs8zt:62 line was updated to CONFIG_ESPTOOLPY_FLASHSIZE_4MB=n
-- Configuring done
-- Generating done
-- Build files have been written to: /root/Projects/moddable/build/tmp/esp32/m5stack_core2/debug/stackchan/xsProj-esp32/build
npm ERR! code ELIFECYCLE
npm ERR! errno 2
npm ERR! stack-chan@0.2.1 debug: `mcconfig -d -m -p ${npm_config_target=esp32/m5stack} ./stackchan/manifest.json`
npm ERR! Exit status 2
npm ERR!
npm ERR! Failed at the stack-chan@0.2.1 debug script.
npm ERR! This is probably not a problem with npm. There is likely additional logging output above.

npm ERR! A complete log of this run can be found in:
```
2. m1(arm64)ホスト上で、amd64イメージからできたコンテナで動いていることが原因？
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

stc1988, 2023-03-19:
M2 macから同様dev containerで実施してみましたが、ビルド成功しました。

エラーログからは`/workspaces/stack-chan/firmware/extern/scservo/src/manifest-driver.json` が存在しないことになっていますが、このファイルは実際に存在していますでしょうか。

DaisukeMiyazaki, 2023-03-21:
@stc1988 ありがとうございます。本issue解決しました、ご指摘ただいた通り`/workspaces/stack-chan/firmware/extern/scservo/src/manifest-driver.json` が存在しておらず、 git clone 時 --recursiveオプションを入れ忘れていたことが原因でした...そのため以下トップ階層で

/stack_chan
`$ git submodule update --init --recursive`
で足りていなかった分をすべてcloneし ビルドし直したところ、上手くビルドできました。

DaisukeMiyazaki, 2023-03-21:
@stc1988 ただ deploy時にUSB接続したm5stack_core2が認識されず...試した手順含め、こちら別issueで扱おうと思います。

meganetaaan, 2023-03-21:
解決できてよかったです！

`--recursive`オプション忘れちゃいますよね…。gitサブモジュールは初心者の方に易しくないので、このリポジトリにソースコードを集約して廃止したいと考えています。

参考：https://github.com/meganetaaan/stack-chan/issues/94

Closed 2023-03-21.

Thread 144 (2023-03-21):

m1mac上のdevcontainerからdeployが上手くいかない

DaisukeMiyazaki, 2023-03-21:
**不具合の概要**
m5stack_core2hrdevcontainerからdeployがうまくいかない

**再現手順**
不具合を再現できる手順を記述してください
1. devcontainer 中で`npm run build --target=esp32/m5stack_core2`の後で、`npm run deploy --target=esp32/m5stack_core2`を実行する
2.
A fatal error occurred: Failed to connect to ESP32: No serial data received.というエラーが発生する

**想定する挙動**
deployが上手く走り、hostがm5stack_core2へ書き込まれる

**ログ**

```
root@docker-desktop:/workspaces/stack-chan/firmware# npm run deploy --target=esp32/m5stack_core2

> stack-chan@0.2.1 deploy /workspaces/stack-chan/firmware
> mcconfig -d -m -p ${npm_config_target=esp32/m5stack} -t deploy ./stackchan/manifest.json

/opt/esp/idf/tools/idf.py
/root/Projects/moddable/build/tmp/esp32/m5stack_core2/debug/stackchan/makefile:2127: warning: overriding recipe for target '/root/Projects/moddable/build/tmp/esp32/m5stack_core2/debug/stackchan/ftimage.h.xsi'
/root/Projects/moddable/build/tmp/esp32/m5stack_core2/debug/stackchan/makefile:2058: warning: ignoring old recipe for target '/root/Projects/moddable/build/tmp/esp32/m5stack_core2/debug/stackchan/ftimage.h.xsi'
# uploading to esp32
[1/5] cd /root/Projects/moddable/build/tmp/esp32/m5stack_core2/debug/stackchan/xsProj-esp32/build/esp-idf/esptool_py && /opt/esp/python_env/idf4.4_py3.8_env/bin/python /opt/esp/idf/components/partition_table/check_sizes.py --offset 0x8000 partition --type app /root/Projects/moddable/build/tmp/esp32/m5stack_core2/debug/stackchan/xsProj-esp32/build/partition_table/partition-table.bin /root/Projects/moddable/build/tmp/esp32/m5stack_core2/debug/stackchan/xsProj-esp32/build/xs_esp32.bin
xs_esp32.bin binary size 0x1df790 bytes. Smallest app partition is 0x200000 bytes. 0x20870 bytes (6%) free.
[2/5] Performing build step for 'bootloader'
[1/1] cd /root/Projects/moddable/build/tmp/esp32/m5stack_core2/debug/stackchan/xsProj-esp32/build/bootloader/esp-idf/esptool_py && /opt/esp/python_env/idf4.4_py3.8_env/bin/python /opt/esp/idf/components/partition_table/check_sizes.py --offset 0x8000 bootloader 0x1000 /root/Projects/moddable/build/tmp/esp32/m5stack_core2/debug/stackchan/xsProj-esp32/build/bootloader/bootloader.bin
Bootloader binary size 0x4420 bytes. 0x2be0 bytes (39%) free.
[2/3] cd /opt/esp/idf/components/esptool_py && /opt/esp/tools/cmake/3.23.1/bin/cmake -D IDF_PATH="/opt/esp/idf" -D SERIAL_TOOL="/opt/esp/python_env/idf4.4_py3.8_env/bin/python /opt/esp/idf/components/esptool_py/esptool/esptool.py --chip esp32" -D SERIAL_TOOL_ARGS="--before=default_reset --after=hard_reset write_flash @flash_args" -D WORKING_DIRECTORY="/root/Projects/moddable/build/tmp/esp32/m5stack_core2/debug/stackchan/xsProj-esp32/build" -P /opt/esp/idf/components/esptool_py/run_serial_tool.cmake
esptool.py esp32 -p /dev/ttyAMA0 -b 1500000 --before=default_reset --after=hard_reset write_flash --flash_mode dio --flash_freq 80m --flash_size 8MB 0x1000 bootloader/bootloader.bin 0x10000 xs_esp32.bin 0x8000 partition_table/partition-table.bin
esptool.py v3.3.2
Serial port /dev/ttyAMA0
Connecting......................................

A fatal error occurred: Failed to connect to ESP32: No serial data received.
For troubleshooting steps visit: https://docs.espressif.com/projects/esptool/en/latest/troubleshooting.html
CMake Error at run_serial_tool.cmake:56 (message):
  /opt/esp/python_env/idf4.4_py3.8_env/bin/python
  /opt/esp/idf/components/esptool_py/esptool/esptool.py --chip esp32 failed

FAILED: CMakeFiles/flash /root/Projects/moddable/build/tmp/esp32/m5stack_core2/debug/stackchan/xsProj-esp32/build/CMakeFiles/flash
cd /opt/esp/idf/components/esptool_py && /opt/esp/tools/cmake/3.23.1/bin/cmake -D IDF_PATH="/opt/esp/idf" -D SERIAL_TOOL="/opt/esp/python_env/idf4.4_py3.8_env/bin/python /opt/esp/idf/components/esptool_py/esptool/esptool.py --chip esp32" -D SERIAL_TOOL_ARGS="--before=default_reset --after=hard_reset write_flash @flash_args" -D WORKING_DIRECTORY="/root/Projects/moddable/build/tmp/esp32/m5stack_core2/debug/stackchan/xsProj-esp32/build" -P /opt/esp/idf/components/esptool_py/run_serial_tool.cmake
ninja: build stopped: subcommand failed.
ninja failed with exit code 1
Executing action: flash
Running ninja in directory /root/Projects/moddable/build/tmp/esp32/m5stack_core2/debug/stackchan/xsProj-esp32/build
Executing "ninja flash"...
```

**スクリーンショット**
host OS側では m5stack_core2 は /dev/以下に認識されている (UARTでは出てこないがm5burner, arduinoではこのデバイスポートから接続できる)
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

container側では /dev/以下にusbserial が反映されていない
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

元々自動で登録される/dev/ttyAMA0 には日時が更新されている模様だが、こちらがUSBserial port用なのか不明
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

**環境 (次の項目を埋めてください):**

- OS: [MacOS , m1 chip]
- IDE: [VSCode]
- M5Stack_core2

**その他**

- [実際のリンクではなくsymlinkしてdocker runすれば上手くいく](https://itecnote.com/tecnote/linux-exposing-a-tty-device-in-a-docker-container-with-docker-for-mac/
)？dev contaninerでないので、devcontainer.json の mounts: source=/dev/, target=/dev/ に追加が必要？

- [mac0Sから tty serial deviceをexposeしても上手くいかない? ](https://github.com/docker/for-mac/issues/900)
- [rasberrypiならうまくいく？](https://geek.tacoskingdom.com/blog/63)

#140 の続きです。

stc1988, 2023-03-28:
確かに現状のmac+Dockerだとコンテナ側からホスト(mac)側のデバイスを見るのが難しいようです。

ESP-IDFの[Remote Serial Ports](https://docs.espressif.com/projects/esp-idf/en/latest/esp32/api-guides/tools/idf-docker-image.html#usage)を試してみると`npm run debug`で書き込み自体はできているのですが、その後のマイコン側へのリセットが失敗する（手動で電源off/onすればOK）ので、開発体験としてはよくなさそうです。

あとmac+Dockerだとmac単独環境に比べてビルドが非常に遅いので、個人的にはmac上で環境構築いただくのがおすすめです。

@meganetaaan
Windows+DockerでもCOMポートが見えないかと思いますので、DockerコンテナはLinuxホスト推奨とした方が良いかもしれません。

meganetaaan, 2023-04-01:
@stc1988 ありがとうございます！DockerはLinux以外では非推奨の旨追記しておきます。
@DaisukeMiyazaki お手数ですが[xs-devを使う手順](https://github.com/meganetaaan/stack-chan/blob/dev/v1.0/firmware/docs/getting-started_ja.md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)を試していただけますか？うまく行かない場合はまたぜひご質問ください🙆

DaisukeMiyazaki, 2023-04-02:
@meganetaaan @stc1988 ご対応ありがとうございます！macローカル環境でxs-devを使う手順で実行したところ、upload portの再設定などCLI上で必要でしたが、うまくいきました！ありがとうございました！

Closed 2023-04-02.

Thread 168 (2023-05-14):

アプリ領域のパーティションサイズが不足している

stc1988, 2023-05-14:
**不具合の概要**

新規機能追加のために` "$(MODDABLE)/examples/pins/audioout/elevenlabs-stream/manifest_elevenlabsstreamer.json"`などをincludeしてビルドするとエラーとなる

**ログ**

```
FAILED: esp-idf/esptool_py/CMakeFiles/app_check_size /Users/satoshi/Projects/moddable/build/tmp/esp32/m5stack_core2/debug/stackchan/xsProj-esp32/build/esp-idf/esptool_py/CMakeFiles/app_check_size
cd /Users/satoshi/Projects/moddable/build/tmp/esp32/m5stack_core2/debug/stackchan/xsProj-esp32/build/esp-idf/esptool_py && /Users/satoshi/.espressif/python_env/idf4.4_py3.8_env/bin/python /Users/satoshi/.local/share/esp32/esp-idf/components/partition_table/check_sizes.py --offset 0x8000 partition --type app /Users/satoshi/Projects/moddable/build/tmp/esp32/m5stack_core2/debug/stackchan/xsProj-esp32/build/partition_table/partition-table.bin /Users/satoshi/Projects/moddable/build/tmp/esp32/m5stack_core2/debug/stackchan/xsProj-esp32/build/xs_esp32.bin
Error: app partition is too small for binary xs_esp32.bin size 0x208f80:
  - Part 'factory' 0/0 @ 0x10000 size 0x200000 (overflow 0x8f80)
ninja: build stopped: subcommand failed.
ninja failed with exit code 1
```

**その他**

[customPartitions.csv](https://github.com/meganetaaan/stack-chan/blob/dev/v1.0/firmware/stackchan/sdkconfig/customPartitions.csv) を使用する場合(core2)には、アプリ領域が2MBとなっているためサイズ不足していると思われる。

meganetaaan, 2023-05-16:
報告ありがとうございます。MODの領域をなるべく確保したくてアプリ領域を必要最小限にしていました。
ホスト側に組み込むモジュールを増やすに従い、都度ホスト領域を拡大する方針としたいと思います。

stc1988, 2023-05-18:
必要に応じて都度拡大で承知しました。

若干別件ですが、`sdkconfig.defaults`でFLASHのサイズを拡張していますが、[core2のもの](https://github.com/Moddable-OpenSource/moddable/blob/fece720ad1456ad571fa4582560c3ecf7d9d7400/build/devices/esp32/targets/m5stack_core2/sdkconfig/sdkconfig.defaults)はFLASH拡張とPSRAMを使用するように変更されたので、stack-chan側での変更は不要そうです。

stc1988, 2023-09-21:
#171 がマージされ容量を拡張したのでクローズします

Closed 2023-09-21.

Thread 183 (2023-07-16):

ファームウェアビルド時のエラー

taisan11, 2023-07-16:
**不具合の概要**
ファームウェアをビルドした際にエラーが発生する

**再現手順**
不具合を再現できる手順を記述してください
1.`npm i`をしてvisualstudioを入れ`npm run setup`はvisualstudiocommandpalletv17.6.5で、`npm run setup -- --device=esp32`は`npm run setup`で出てきた新しいコマンドプロンプトで実行し、
1. [これ](https://github.com/meganetaaan/stack-chan/blob/dev/v1.0/firmware/docs/flashing-firmware_ja.md)の`npm run build --target=esp32/m5stack_core2`をESP-IDF 5.1 CMDで実行する
2. 下のようなエラーが発生する

**ログ**

```log
> stack-chan@0.2.1 build
> cross-env npm_config_target?=esp32/m5stack cross-env-shell mcconfig -d -m -p \$npm_config_target -t build ./stackchan/manifest_local.json

C:\Espressif\tools\idf-exe\1.0.3\idf.py.exe
C:\Espressif\frameworks\esp-idf-v5.1\tools\idf.py
*** Update required to ESP-IDF v4.4.3 (found v5.1)
  See update instructions at: https://github.com/Moddable-OpenSource/moddable/blob/public/documentation/devices/esp32.md
"Expected ESP IDF v4.4.3, found v5.1"
NMAKE : fatal error U1077: 'python C:\Users\ユーザー名\xs-dev\moddable\build\devices\esp32\xsProj-esp32\versionCheck.py v4.4.3 v5.1 || (echo "Expected ESP IDF v4.4.3, found v5.1" && exit 1)' : リターン コード '0x1'
Stop.
```

**環境:**

- OS: Windows11
- IDE: ESP-IDF?
- ｽﾀｯｸﾁｬﾝのバージョン:dev/v1.0
- M5Stack Core2

stc1988, 2023-07-20:
ESP IDFの`v5.1`がインストールされているようですが、現在Moddableで対応しているのは`v4.4.3`です。
インストール方法については[Moddable公式ドキュメント](https://github.com/Moddable-OpenSource/moddable/blob/public/documentation/devices/esp32.md#windows)を参照ください

taisan11, 2023-07-22:
ESP-IDFv4.4.3のコマンドプロンプト内で`C:\Users\kappy\xs-dev\Moddable.bat`を実行し`npm run build --target=esp32/m5stack_core2`を実行したところ以下のようなエラーが発生します
```
-- Configuring incomplete, errors occurred!
See also "C:/Users/user/xs-dev/moddable/build/tmp/esp32/m5stack_core2/debug/stackchan/xsProj-esp32/build/CMakeFiles/CMakeOutput.log".
cmake failed with exit code 1
NMAKE : fatal error U1077: 'python %IDF_PATH%\tools\idf.py -n reconfigure -D SDKCONFIG_DEFAULTS=C:/Users/user/xs-dev/moddable/build/tmp/esp32/m5stack_core2/debug/stackchan/xsProj-esp32/sdkconfig.mc -D SDKCONFIG_HEADER="C:\Users\user\xs-dev\moddable\build\tmp\esp32\m5stack_core2\debug\stackchan\xsProj-esp32\build\config\sdkconfig.h" -D CMAKE_MESSAGE_LOG_LEVEL=ERROR -D DEBUGGER_SPEED=1500000 -D IDF_TARGET=esp32 -D ESP32_SUBCLASS=esp32 -D SDKCONFIG_DEFAULTS=C:\Users\user\xs-dev\moddable\build\tmp\esp32\m5stack_core2\debug\stackchan\xsProj-esp32\sdkconfig.mc' : リターン コード '0x2'
Stop.
```
生成されたログは以下の通りです
https://gist.github.com/taisan11/b621128f20267c9a0b9f16ff1df9625d

stc1988, 2023-08-01:
確認遅くなりすみません。
いただいたログからも手がかりがないので`npm run doctor`を実行して環境が構築できているか確認いただけますでしょうか

taisan11, 2023-08-02:
`npm run doctor`を実行してみましたが特におかしい点はありませんでした
以下実行ログです
```
stack-chan environment info:
4bf78b32f11bdd3457a3826fd247a2dfeb99e808
C:/Users/kappy/Documents/stack-chan
xs-dev environment info:
  CLI Version                0.20.0
  OS                         Windows_NT
  Arch                       x64
  NodeJS Version             v18.16.0 (C:\Program Files\nodejs\node.EXE)
  Python Version             3.8.7 (C:\Espressif\python_env\idf4.4_py3.8_env\Scripts\python.EXE)
  Moddable SDK Version       3.9.2 (C:\Users\kappy\xs-dev\moddable)
  Supported target devices   win, esp32
  ESP32 IDF Directory        C:\Users\kappy\xs-dev\esp32\esp-idf

If this is related to an error when using the CLI, please create an issue at "https://github.com/hipsterbrown/xs-dev/issues/new" with the above info.
```

stc1988, 2023-08-02:
環境構築はxs-devを使って実施してそうですね。私のほうでも試してみますが、Windows環境のxs-devはサポート状況が完全でなく、動作しない可能性もあります。

[Windows環境においては[公式の手順](https://github.com/Moddable-OpenSource/moddable/blob/public/documentation/devices/esp32.md#win-instructions)を実施し他が早回りかもしれません。

@washishi  本件のような事象に遭遇したことはありますでしょうか

washishi, 2023-08-02:
Windowsの場合 xs-dev というか ESP-IDF Windows InstallerでPython3.8.7が入りそれが使われるのですがそのPythonに問題がある様でｽﾀｯｸﾁｬﾝのファームウエアのビルドは失敗します
なので利用するPythonを変更する必要があります

下記メモを作ってますので参照してみてください
[Windowsでのxs-devを利用したmodableビルド環境構築](https://docs.google.com/document/d/1d9tJtlop8iQA_WK1ZvKx-tOoo5K1ntlmiUGx0NkkASc/edit?usp=sharing)

利用するPythonの変更については「・ESP-IDF Tools で利用するPythonの変更」のところで書いてます

washishi, 2023-08-02:
【参考】ビルドで失敗する件のメッセージの詳細はこちらで書いてましたね
https://github.com/meganetaaan/stack-chan/issues/136#issuecomment-1485041097

Closed 2025-04-25.

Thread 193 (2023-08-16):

M5Stack Core2 Microphone replace？Schematics have not found replace microphone

pickmonster100, 2023-08-16:
ご尽力と共有ありがとうございます。M5Stack Core2オリジナルの開発ソケット バージョンにはマイクがありましたが、オープンソース設計の PCB ボードに置き換えると、設計されたマイクがなくなりました。サウンドを録音するにはどうすればよいですか?

meganetaaan, 2023-08-24:
試してくださりありがとうございます！
ご指摘の通りM5Stack Core2はボトム基板側にマイクがあるため、ｽﾀｯｸﾁｬﾝ基板を刺すとマイクが使えなくなります。
[pdmマイクユニット](https://www.switch-science.com/products/6620?_pos=2&_sid=38aeec5c3&_ss=r/)を別途刺して使うか、本体側にマイクが搭載されている[M5Stack CoreS3](https://www.switch-science.com/products/8960)をお使いいただく必要があります。

なお、本リポジトリのサンプルコードにはサウンド録音の機能はまだありませんのでご注意ください。
会話機能を試したい場合、 @robo8080 さんの「[AIｽﾀｯｸﾁｬﾝ](https://github.com/robo8080/AI_StackChan2)」でしたら本体のマイクを使った音声認識が可能です。

Closed 2023-09-06.

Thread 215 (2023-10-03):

Stack-chan fails to build on Moddable v4.2.0

meganetaaan, 2023-10-03:
**Describe the bug**
Stack-chan fails to build on Moddable v4.2.0

**To Reproduce**
Steps to reproduce the behavior:
1. Update Moddable SDK to v4.2.0
2. Update ESP-IDF to v5.1.1
3. run `npm run debug`

**Logs**
If any compile error occurs, add a full compile log.

`pins/servo` module seems to be incompatible with the latest ESP-IDF (v5.1.1)

````log
# cc modServo.c.o
# cc crc.c.o
/home/sskw/.local/share/moddable/modules/pins/servo/esp32/modServo.c: In function 'xs_servo':
/home/sskw/.local/share/moddable/modules/pins/servo/esp32/modServo.c:58:18: error: 'ledc_timer_config_t' has no member named 'bit_num'
   58 |                 .bit_num = LEDC_TIMER_14_BIT,
      |                  ^~~~~~~
make: *** [/home/sskw/.local/share/moddable/build/tmp/esp32/m5stack/debug/stackchan/makefile:2591: /home/sskw/.local/share/moddable/build/tmp/esp32/m5stack/debug/stackchan/modServo.c.o] エラー 1
make: *** 未完了のジョブを待っています....
# cc modules.c.o
````

<details>
<summary>complete log</summary>

```
[sskw]$ npm run debug target=esp32/m5stack_core2    

> stack-chan@0.2.1 debug /work/ghq/github.com/meganetaaan/stack-chan/firmware
> cross-env npm_config_target?=esp32/m5stack cross-env-shell mcconfig -d -m -p \$npm_config_target ./stackchan/manifest_local.json "target=esp32/m5stack_core2"

mcconfig: mod partition of size 0x40000 created from factory app partition
mcconfig: file storage partition of size 0x10000 created from factory app partition
/home/sskw/.local/share/esp32/esp-idf-v5.1.1/tools/idf.py
/home/sskw/.local/share/moddable/build/tmp/esp32/m5stack/debug/stackchan/makefile:2376: 警告: ターゲット '/home/sskw/.local/share/moddable/build/tmp/esp32/m5stack/debug/stackchan/ftimage.h.xsi' のためのレシピを置き換えます
/home/sskw/.local/share/moddable/build/tmp/esp32/m5stack/debug/stackchan/makefile:2307: 警告: ターゲット '/home/sskw/.local/share/moddable/build/tmp/esp32/m5stack/debug/stackchan/ftimage.h.xsi' のための古いレシピは無視されます
# bles2gatt bleservices
Using recommended ESP-IDF v5.1.1
# xsc Resource.xsb
# xsc ili9341.xsb
# xsc m5button.xsb
# xsc time.xsb
# xsc timer.xsb
# xsc modules.xsb
# xsc crc.xsb
# xsc net.xsb
# xsc socket.xsb
# xsc sntp.xsb
# xsc wifi.xsb
# xsc preference.xsb
# xsc structuredClone.xsb
# xsc deepEqual.xsb
# xsc bleserver.xsb
# xsc btutils.xsb
# xsc gap.xsb
# xsc gapwhitelist.xsb
# xsc sm.xsb
# xsc bleclient.xsb
# xsc connection.xsb
# xsc gatt.xsb
# xsc uartserver.xsb
# xsc stk-server.xsb
# xsc crypt.xsb
# xsc base64.xsb
# xsc hex.xsb
# xsc ec.xsb
# xsc ecp.xsb
# xsc modular.xsb
# xsc mont.xsb
# xsc tlssocket.xsb
# xsc fetch.xsb
# xsc config.xsb
# xsc logical.xsb
# xsc WebSocket.xsb
# xsc mdns.xsb
# xsc dns.xsb
# xsc resourcestreamer.xsb
# xsc mp3streamer.xsb
# xsc elevenlabsstreamer.xsb
# xsc wavstreamer.xsb
# xsc sbcstreamer.xsb
# xsc calculate-power.xsb
# xsc pins/digital.xsb
# xsc commodetto/Bitmap.xsb
# xsc pins/digital/monitor.xsb
# xsc pins/audioout.xsb
# xsc setup/target.xsb
# xsc m5stack/screen.xsb
# xsc pins/servo.xsb
# xsc setup/network.xsb
# xsc ~.embedded/io/analog.xsb
# xsc ~.embedded/io/digital.xsb
# xsc ~.embedded/io/digitalbank.xsb
# xsc ~.embedded/io/i2c.xsb
# xsc ~.embedded/implementation/i2csync.xsb
# xsc ~.embedded/io/smbus.xsb
# xsc ~.embedded/implementation/smbussync.xsb
# xsc ~.embedded/io/pwm.xsb
# xsc ~.embedded/io/serial.xsb
# xsc ~.embedded/io/spi.xsb
# xsc ~.embedded/io/socket/tcp.xsb
# xsc ~.embedded/io/socket/udp.xsb
# xsc ~.embedded/io/socket/listener.xsb
# xsc system.xsb
# xsc ~.embedded/provider/builtin.xsb
# xsc ~.embedded/io/pulsecount.xsb
# xsc ~.embedded/io/pulsewidth.xsb
# xsc headers.xsb
# xsc url.xsb
# xsc ~.embedded/network/dns/resolver/udp.xsb
# xsc dns/parser.xsb
# xsc dns/serializer.xsb
# xsc httpclient/config.xsb
# xsc ~.embedded/network/http/client.xsb
# xsc bin.xsb
# xsc ssl/alert.xsb
# xsc ssl/cache.xsb
# xsc ssl/cert.xsb
# xsc ssl/changecipher.xsb
# xsc ssl/ciphersuites.xsb
# xsc ssl/constants.xsb
# xsc ssl/error.xsb
# xsc ssl/handshake.xsb
# xsc ssl/prf.xsb
# xsc ssl/record.xsb
# xsc ssl/setup.xsb
# xsc ssl/stream.xsb
# xsc ber.xsb
# xsc curve.xsb
# xsc dsa.xsb
# xsc ecdsa.xsb
# xsc gcm.xsb
# xsc hmac.xsb
# xsc pkcs1_5.xsb
# xsc pkcs1.xsb
# xsc pkcs8.xsb
# xsc rng.xsb
# xsc rsa.xsb
# xsc x509.xsb
# xsc ssl/session.xsb
# xsc httpsclient/config.xsb
# xsc commodetto/parseBMF.xsb
# xsc commodetto/parseBMP.xsb
# xsc commodetto/parseRLE.xsb
# xsc commodetto/Poco.xsb
# xsc commodetto/PocoCore.xsb
# xsc setup/commodetto.xsb
# xsc commodetto/outline.xsb
# xsc commodetto/pocoOutline.xsb
# xsc text/decoder.xsb
# xsc ~.embedded/network/websocket/client.xsb
# xsc mp3/decode.xsb
# xsc file.xsb
# xsc data/wavreader.xsb
# xsc mc/config.xsb
# tsc tsconfig.json
# xsid Resource.c.xsi
# xsid modGPIO.c.xsi
# xsid modSPI.c.xsi
# xsid modIli9341.c.xsi
# xsid modMonitor.c.xsi
# xsid modTime.c.xsi
# xsid modTimer.c.xsi
# xsid timer.c.xsi
# xsid modPreference.c.xsi
# xsid modInstrumentation.c.xsi
# xsid modLwipSafe.c.xsi
# xsid modules.c.xsi
# xsid crc.c.xsi
# xsid modServo.c.xsi
# xsid modNet.c.xsi
# xsid modResolve.c.xsi
# xsid modSocket.c.xsi
# xsid modsntp.c.xsi
# xsid xs6wifi.c.xsi
# xsid builtinCommon.c.xsi
# xsid digitalbank.c.xsi
# xsid _i2c.c.xsi
# xsid spi.c.xsi
# xsid structuredClone.c.xsi
# xsid deepEqual.c.xsi
# xsid btutils.c.xsi
# xsid gap.c.xsi
# xsid modBLEServer.c.xsi
# xsid modBLESM.c.xsi
# xsid modBLEGAP.c.xsi
# xsid modBLECommon.c.xsi
# xsid modBLEClient.c.xsi
# xsid moddnsparser.c.xsi
# xsid modCrypt.c.xsi
# xsid chacha.c.xsi
# xsid fips180.c.xsi
# xsid fips197.c.xsi
# xsid fips46.c.xsi
# xsid ghash.c.xsi
# xsid rc.c.xsi
# xsid rfc1321.c.xsi
# xsid modBase64.c.xsi
# xsid modHex.c.xsi
# xsid ec.c.xsi
# xsid modular.c.xsi
# xsid mont.c.xsi
# xsid xsBigIntEx.c.xsi
# xsid ftcalc.c.xsi
# xsid ftgrays.c.xsi
# xsid ftraster.c.xsi
# xsid ftstroke.c.xsi
# xsid fttrigon.c.xsi
# xsid ftutil.c.xsi
# xsid modLogical.c.xsi
# xsid bit.c.xsi
# xsid fixed.c.xsi
# xsid frame.c.xsi
# xsid huffman.c.xsi
# xsid layer3.c.xsi
# xsid stream.c.xsi
# xsid synth.c.xsi
# xsid mad_timer.c.xsi
# xsid lfs.c.xsi
# xsid lfs_util.c.xsi
# xsid modLittlefs.c.xsi
# xsid wavstreamer.c.xsi
# xsid calculatePower.c.xsi
# xsid digital.c.xsi
# xsid commodettoBitmap.c.xsi
# xsid audioout.c.xsi
# xsid dvi_adpcm_decode.c.xsi
# xsid sbc_decoder.c.xsi
# xsid commodettoPocoBlit.c.xsi
# xsid _analog.c.xsi
# xsid _pwm.c.xsi
# xsid serial.c.xsi
# xsid tcp.c.xsi
# xsid udp.c.xsi
# xsid system.c.xsi
# xsid _pulsecount.c.xsi
# xsid _pulsewidth.c.xsi
# xsid url.c.xsi
# xsid bin.c.xsi
# xsid rng.c.xsi
# xsid x509.c.xsi
# xsid commodettoParseBMF.c.xsi
# xsid commodettoParseBMP.c.xsi
# xsid commodettoParseRLE.c.xsi
# xsid commodettoPocoCore.c.xsi
# xsid cfeBMF.c.xsi
# xsid commodettoOutline.c.xsi
# xsid commodettoPocoOutline.c.xsi
# xsid textdecoder.c.xsi
# xsid mp3.c.xsi
# xsid modGPIO.h.xsi
# xsid modSPI.h.xsi
# xsid modTimer.h.xsi
# xsid modPreference.h.xsi
# xsid modInstrumentation.h.xsi
# xsid modLwipSafe.h.xsi
# xsid modSocket.h.xsi
# xsid builtinCommon.h.xsi
# xsid modBLE.h.xsi
# xsid modBLECommon.h.xsi
# xsid chacha.h.xsi
# xsid fips180.h.xsi
# xsid fips197.h.xsi
# xsid fips46.h.xsi
# xsid ghash.h.xsi
# xsid kcl.h.xsi
# xsid kcl_symmetric.h.xsi
# xsid rc.h.xsi
# xsid rfc1321.h.xsi
# xsid xsBigIntEx.h.xsi
# xsid ftgrays.h.xsi
# xsid ftimage.h.xsi
# xsid ftmisc.h.xsi
# xsid ftraster.h.xsi
# xsid rasterrs.h.xsi
# xsid ft2build.h.xsi
# xsid freetype.h.xsi
# xsid ftadvanc.h.xsi
# xsid ftbbox.h.xsi
# xsid ftbdf.h.xsi
# xsid ftbitmap.h.xsi
# xsid ftbzip2.h.xsi
# xsid ftcache.h.xsi
# xsid ftchapters.h.xsi
# xsid ftcid.h.xsi
# xsid ftcolor.h.xsi
# xsid ftdriver.h.xsi
# xsid fterrdef.h.xsi
# xsid fterrors.h.xsi
# xsid ftfntfmt.h.xsi
# xsid ftgasp.h.xsi
# xsid ftglyph.h.xsi
# xsid ftgxval.h.xsi
# xsid ftgzip.h.xsi
# xsid ftincrem.h.xsi
# xsid ftlcdfil.h.xsi
# xsid ftlist.h.xsi
# xsid ftlogging.h.xsi
# xsid ftlzw.h.xsi
# xsid ftmac.h.xsi
# xsid ftmm.h.xsi
# xsid ftmodapi.h.xsi
# xsid ftmoderr.h.xsi
# xsid ftotval.h.xsi
# xsid ftoutln.h.xsi
# xsid ftparams.h.xsi
# xsid ftpfr.h.xsi
# xsid ftrender.h.xsi
# xsid ftsizes.h.xsi
# xsid ftsnames.h.xsi
# xsid ftstroke.h.xsi
# xsid ftsynth.h.xsi
# xsid ftsystem.h.xsi
# xsid fttrigon.h.xsi
# xsid fttypes.h.xsi
# xsid ftwinfnt.h.xsi
# xsid t1tables.h.xsi
# xsid ttnameid.h.xsi
# xsid tttables.h.xsi
# xsid tttags.h.xsi
# xsid autohint.h.xsi
# xsid cffotypes.h.xsi
# xsid cfftypes.h.xsi
# xsid compiler-macros.h.xsi
# xsid ftcalc.h.xsi
# xsid ftdebug.h.xsi
# xsid ftdrv.h.xsi
# xsid ftgloadr.h.xsi
# xsid fthash.h.xsi
# xsid ftmemory.h.xsi
# xsid ftobjs.h.xsi
# xsid ftpsprop.h.xsi
# xsid ftrfork.h.xsi
# xsid ftserv.h.xsi
# xsid ftstream.h.xsi
# xsid fttrace.h.xsi
# xsid ftvalid.h.xsi
# xsid bit.h.xsi
# xsid fixed.h.xsi
# xsid frame.h.xsi
# xsid huffman.h.xsi
# xsid layer3.h.xsi
# xsid stream.h.xsi
# xsid synth.h.xsi
# xsid lfs.h.xsi
# xsid lfs_util.h.xsi
# xsid commodettoBitmap.h.xsi
# xsid sbc_decoder.h.xsi
# xsid commodettoPocoBlit.h.xsi
# xsid commodettoPoco.h.xsi
# xsid commodettoPocoOutline.h.xsi
# copy ca233.der
# copy ca.ski
# png2bmp OpenSans-Regular-24-alpha.bmp
# wav2maud bflatmajor.maud
# Reconfiguring ESP-IDF...
# compressbmf OpenSans-Regular-24.bf4
Executing action: reconfigure
Running cmake in directory /home/sskw/.local/share/moddable/build/tmp/esp32/m5stack/debug/stackchan/xsProj-esp32/build
Executing "cmake -G Ninja -DPYTHON_DEPS_CHECKED=1 -DPYTHON=/home/sskw/.espressif/python_env/idf5.1_py3.10_env/bin/python -DESP_PLATFORM=1 -DSDKCONFIG_DEFAULTS=/home/sskw/.local/share/moddable/build/tmp/esp32/m5stack/debug/stackchan/xsProj-esp32/sdkconfig.mc -DSDKCONFIG_HEADER=/home/sskw/.local/share/moddable/build/tmp/esp32/m5stack/debug/stackchan/xsProj-esp32/build/config/sdkconfig.h -DCMAKE_MESSAGE_LOG_LEVEL=ERROR -DDEBUGGER_SPEED=460800 -DIDF_TARGET=esp32 -DESP32_SUBCLASS=esp32 -DCCACHE_ENABLE=0 /home/sskw/.local/share/moddable/build/tmp/esp32/m5stack/debug/stackchan/xsProj-esp32"...
# xsc scservo.xsb
# xsc rs30x.xsb
# xsc consts.xsb
# xsc stackchan-util.xsb
# xsc dynamixel-driver.xsb
# xsc dynamixel.xsb
# xsc none-driver.xsb
# xsc rs30x-driver.xsb
# xsc scservo-driver.xsb
# xsc sg90-driver.xsb
# xsc beacon-packet.xsb
# xsc dialogue-chatgpt.xsb
# xsc decorator.xsb
# xsc dog-face.xsb
# xsc modifier.xsb
# xsc renderer-base.xsb
# xsc simple-face.xsb
# xsc network-service.xsb
# xsc preference-server.xsb
# xsc tts-elevenlabs.xsb
# xsc tts-local.xsb
# xsc tts-remote.xsb
# xsc tts-voicevox.xsb
# xsc touch.xsb
# xsc robot.xsb
# xsc main.xsb
# xsc default-mods/mod.xsb
# xsc default-mods/on-launch.xsb
# xsc default-mods/on-robot-created.xsb
Loading defaults file /home/sskw/.local/share/moddable/build/tmp/esp32/m5stack/debug/stackchan/xsProj-esp32/sdkconfig.mc...
-- Configuring done
-- Generating done
-- Build files have been written to: /home/sskw/.local/share/moddable/build/tmp/esp32/m5stack/debug/stackchan/xsProj-esp32/build
# cc xsAll.c (strings in flash)
# cc xsAPI.c (strings in flash)
# cc xsArguments.c (strings in flash)
# cc xsArray.c (strings in flash)
# cc xsAtomics.c (strings in flash)
# cc xsBigInt.c (strings in flash)
# cc xsBoolean.c (strings in flash)
# cc xsCode.c (strings in flash)
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
stc1988, 2023-10-03:
https://github.com/Moddable-OpenSource/moddable/issues/1088

I can't confirm it right now, but hasn't this problem been solved yet?

meganetaaan, 2023-10-03:
I've found that another commit rolled back your fix. I made a PR to get them back.
https://github.com/Moddable-OpenSource/moddable/pull/1225

meganetaaan, 2023-10-03:
I've found several issues that block firmware build.
As a workaround, I'm going to fix the version of ModdableSDK in `npm run setup` script as below.

```
    "setup": "xs-dev setup --target-branch 4.1",
```

stc1988, 2024-08-24:
We have resolved various issues and are currently using the latest version of Moddable. Although there is an issue with the serial servo not working in the latest version, can we create a separate issue for that and close this issue?

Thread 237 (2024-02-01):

m5stack core2 v1.1でファームウェアが全く機能しません

RChikamura, 2024-02-01:
**不具合の概要**
ファームウェアをビルドし、書き込んでみたのですが、画面に何もつかず、モーターも反応しません
ターミナルやデバッガーを見ても、目立ったエラーコードは特に出ていません。

**再現手順**
node js および npm の最新版を導入した環境で、
https://github.com/meganetaaan/stack-chan/blob/dev/v1.0/firmware/docs/getting-started_ja.md
https://github.com/meganetaaan/stack-chan/blob/dev/v1.0/firmware/docs/flashing-firmware_ja.md
のコードを用いて環境構築をし、ファームウェアを書き込みました。

**環境:**

- OS: Windows 11 実機 および Ubuntu仮想環境(VMware) (どちらで試してもダメでした)
- ESP-IDF v5.1.2 および v4.4.3 (v4.4.3はUbuntuでのみテスト)
- ｽﾀｯｸﾁｬﾝのバージョン v1.0
- 使用するM5Stackの種類 m5stack core2 v1.1

**その他**
stack-chan-testerはPlatform IOを通して書き込みに成功しており、画面やモーターなども正しく動作することを確認しています。

meganetaaan, 2024-02-01:
報告ありがとうございます！Core2 v1.1はModdable側がまだ対応しておらず、改修が必要です。
私も手元にテスト用機体はありますが手が回っていない状況でした🙇
今週中を目処に、必要な改修箇所について確認しますね。

RChikamura, 2024-02-18:
私のほうでも独自に調査し、改修をしていたのですが、前進があったので共有いたします
Core2のsetup-target.js, manifest.jsonと、モジュールaxp2101.jsを改修することにより、初期化処理が一部進行するようになった模様です。ただし、タッチパネルのセットアップに失敗しているようで、スタックちゃんの起動までは至らず、下部LEDのみが点灯している状態となります。
https://github.com/RChikamura/Moddable_Repair_RChikamura

RChikamura, 2024-02-25:
さらに修正を加え、プログラムが１回起動するところまでは持っていけましたが、２回目以降は次回正常起動ができず、わずか数秒で落ちてしまう状態になってしまいます。

問題点として、AXP2101.jsにピン設定が大幅に不足していたり、AXP192.jsから変更されていないままの部分があったりしている点が見受けられ、それが影響を及ぼしているように思えます。
https://github.com/RChikamura/Moddable_Repair_RChikamura

RChikamura, 2024-02-29:
さらに修正を加え、おそらく正常起動可能になりました。
https://github.com/RChikamura/moddable_core2v1.1_try

meganetaaan, 2024-03-07:
ありがとうございます！いまコード読んでいます。
AXP2101のDCDCやLDOなど足りていない機能を色々実装してくださったんですね。

DCDCの電圧のステップ数などの設定が[ピンによって違う](https://github.com/RChikamura/moddable_core2v1.1_try/blob/d22782d4398db27bdda5e999d454615cc70303e3/xs-dev/moddable/modules/drivers/axp2101/axp2101.js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)んですね。たしかに[データシート](https://m5stack.oss-cn-shenzhen.aliyuncs.com/resource/docs/datasheet/core/K128%20CoreS3/AXP2101_Datasheet_V1.0_en.pdf)の5.5 （Electrical Characteristics）に書いてますね。

後ほど実機で動かしてみます！

ちなみにModdable本家に今回の対応をコントリビュートするのは興味ありますか？コードを他のデバイスでも動くように修正したり、プルリクエストを作ったりする感じです。慣れない点がありましたら私もサポートできればと思います。

RChikamura, 2024-03-13:
返信遅れて申し訳ございません。
このようにgithubで連携を取って開発を進めたことがなく、まだどのような作業を行えばよいかわかっていないのですが、できることがあればお手伝いしたいと思います。

meganetaaan, 2024-03-17:
私の方でも動作確認ができました！ありがとうございます！

いただいた変更を私の方でModdableに取り込んで微修正し、旧バージョンのCore2と共存して動くようにできました。

https://github.com/meganetaaan/moddable/tree/feature/m5stack_v2.1

Moddable最新版からの差分は下記のプルリクエストのとおりです。
https://github.com/meganetaaan/moddable/pull/1

このあともう少しセルフレビューしたら、RChikamuraさんを「共同編集者」としてModdable本家のほうにプルリクを出そうと思います。その際RChikamuraさんにContributor License Agreement（CLA：Moddableが指定するライセンスでコードを公開してよいですという同意書）を書いていただく必要がありますが、この段階になったらまた連絡します。CLAの詳細は↓にあります。

https://github.com/Moddable-OpenSource/moddable/blob/public/contributing.md#submitting-pull-requests

meganetaaan, 2024-03-22:
プルリク作りました！

https://github.com/Moddable-OpenSource/moddable/pull/1324

@RChikamura 前述の通り、ModdableにCLAを提出していただけますでしょうか。

https://github.com/Moddable-OpenSource/moddable/blob/public/licenses/Moddable%20CLA%20-%20individual.pdf

* PDFを印刷
* 必要事項を記入
* スキャン（私はPDFスキャン機能のついたスマホアプリを使いました）
* info@moddable.com にPDFを送付する

で完了です。ご不明点ありましたらお尋ねください :bow:

meganetaaan, 2024-03-29:
上記のプルリクがマージされました。
https://github.com/Moddable-OpenSource/moddable/pull/1324

既にModdableの`public`ブランチで利用できるほか、来月のModdable月次リリースにもこの修正が含まれる見込みです。

meganetaaan, 2024-05-02:
https://github.com/Moddable-OpenSource/moddable/releases/tag/4.6.0
4月のリリースで修正が取り込まれたので試しているんですが、LCDが付かないですね…なにか修正を間違えたかな。
デバイス本体下の青色LEDがずっと点滅しているのも気になります。

meganetaaan, 2024-05-02:
クローズします。v1.1でまだ問題があれば再オープンしてください。

Closed 2024-05-02.

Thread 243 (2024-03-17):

音量を設定できるようにする

stc1988, 2024-03-17:
https://github.com/meganetaaan/stack-chan/issues/204 の残課題

**Is your feature request related to a problem? Please describe.**

TTSなどでｽﾀｯｸﾁｬﾝから音声出力時の音量を変更できるようにする。

**Describe the solution you'd like**

AudioOutで音量を変更するには、[audio.enqueue](https://github.com/Moddable-OpenSource/moddable/blob/a6a71b225bd35201ec76b2c354b7595a1be2ed12/documentation/pins/audioout.md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)時に指定する方法があるが、`xxxStreamer`内で指定しているため拡張が必要？

M5stackCoreS3の場合は[AW88298](https://github.com/Moddable-OpenSource/moddable/blob/a6a71b225bd35201ec76b2c354b7595a1be2ed12/build/devices/esp32/targets/m5stack_cores3/setup-target.js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)から設定が可能？

**Additional context**

`manifest_json`の`config`から指定する場合や、NVSで設定値を保持する場合、 [Preferenceのキー](https://github.com/meganetaaan/stack-chan/blob/dev/v1.0/firmware/stackchan/utilities/consts.ts#L9)が未定義であるため定義が必要。

stc1988, 2024-10-22:
#291 でAudioOutインスタンスを都度生成するようになったので、そのタイミングで音量をセットすることができそう。
と同時にToneクラスも誕生したため、stack-chan一律での音量設定よりはクラスごとのインスタンス変数として音量を保持、設定できるようにした方がよい。

meganetaaan, 2025-01-06:
音量に関する要求事項として以下が考えられます

- ｽﾀｯｸﾁｬﾝを置く環境によって、後から音量を変えられるようにしたい
- 一部の音声（通知音など）は上記設定に関わらず固定の音量を与えられるようにしたい

実装方針を考えてみました

- TTSの各クラスとToneに音量セットの機能を追加する
- コンストラクタ引数にオプションvolumeを足す
- Robotクラスに音量の変数を追加する
- configに音量設定を追加する→`config.tts.volume`
- Robot#sayの第2引数で音量をオーバーライドできる

stc1988, 2025-06-07:
対対応したのでクローズします

Closed 2025-06-07.

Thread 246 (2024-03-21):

WebブラウザからM5Stack CoreS3へのファームウェア書き込みに失敗する

meganetaaan, 2024-03-21:
**不具合の概要**

[Webサイトからのｽﾀｯｸﾁｬﾝファームウェア書き込み](https://meganetaaan.github.io/stack-chan/web/flash/) 機能がM5Stack CoreS3では失敗します。

**再現手順**
1. PCとM5Stack CoreS3をUSB接続する
2. https://meganetaaan.github.io/stack-chan/web/flash/ を開く
3. ターゲットデバイスに「M5Stack CoreS3」を選択する
4. "Flash Stack-chan Firmware" ボタンを押下してシリアルポートを選択する
5. "Install Stack-chan"を選択する
6. "Your ESP32S3 board is not supported"というエラーが出て書き込みに失敗する

**想定する挙動**
正しくファームウェアの書き込みができる

**ログ**

書き込み失敗するときのWeb開発者ツールのコンソールのログは下記の通り

```log
ESP Web Tools 9.4.3 by Nabu Casa; https://esphome.github.io/esp-web-tools/
install-dialog-28H-HNrD.js?module:424 Initializing Improv Serial
install-dialog-28H-HNrD.js?module:724 Improv initialization failed. Error: Improv Wi-Fi Serial not detected
    at install-dialog-28H-HNrD.js?module:424:1355
_initialize @ install-dialog-28H-HNrD.js?module:724
install-dialog-28H-HNrD.js?module:424 esptool.js
install-dialog-28H-HNrD.js?module:424 Serial port WebSerial VendorID 0x303a ProductID 0x1001
install-dialog-28H-HNrD.js?module:424 Connecting...
install-dialog-28H-HNrD.js?module:424 .
install-dialog-28H-HNrD.js?module:424

install-dialog-28H-HNrD.js?module:424 Detecting chip type...
install-dialog-28H-HNrD.js?module:424 ESP32-S3
install-dialog-28H-HNrD.js?module:424 Chip is ESP32-S3
install-dialog-28H-HNrD.js?module:424 Features: Wi-Fi,BLE
install-dialog-28H-HNrD.js?module:424 Crystal is 40MHz
install-dialog-28H-HNrD.js?module:424 MAC: 48:27:e2:66:e0:34
install-dialog-28H-HNrD.js?module:424 Uploading stub...
install-dialog-28H-HNrD.js?module:424 Running stub...
install-dialog-28H-HNrD.js?module:424 Stub running...
install-dialog-28H-HNrD.js?module:424 Manufacturer: 20
install-dialog-28H-HNrD.js?module:424 Device: 4018
install-dialog-28H-HNrD.js?module:424 Detected flash size: 16MB
install-dialog-28H-HNrD.js?module:724 Uncaught (in promise) DOMException: Failed to execute 'open' on 'SerialPort': The port is already open.
    at https://unpkg.com/esp-web-tools@9.4.3/dist/web/install-dialog-28H-HNrD.js?module:724:6424
```

**環境 (次の項目を埋めてください):**

- OS: Linux
- ブラウザ: Google Chrome バージョン: 112.0.5615.165（Official Build） （64 ビット）
- ｽﾀｯｸﾁｬﾝのバージョン `dev/v1.0`最新
- 使用するM5Stackの種類 M5Stack CoreS3

meganetaaan, 2024-03-21:
ESP Web Toolsの公式サイトのライブデモ（https://esphome.github.io/esp-web-tools/）からはCoreS3に正しく書き込みができる。

ｽﾀｯｸﾁｬﾝのESP Web Toolsはバージョン9.4.3、公式サイトは10.0.1。単にバージョンを最新にすると解決するかも。

stc1988, 2024-03-21:
本issueと同様の事象が再現できました。

[esptool-js](https://github.com/espressif/esptool-js)側のアップデートかもしれないですが、ESP Web Toolsを最新にしてみるで良い気はします。

meganetaaan, 2024-03-22:
プルリク作りました。結局esp-web-tool用のマニフェストファイルに不備があり、チップファミリーの指定とブートローダーを書き込むオフセットが間違っていました。オフセットについてはビルド時の情報から自動で抽出する案もありましたがまだベタ書きですね…

Closed 2024-03-23.

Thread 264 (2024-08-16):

@moddable/typings パッケージを使用する

stc1988, 2024-08-16:
**既存の機能に問題がある場合、その説明**

#116にて`tsconfig.json`からModdableの標準モジュールのtypingsを相対パスで指定できない問題が発生するため、#117 で`tsconfig.json`をビルド時に生成されるものをコピーするようにしました。

しかし、[ @moddable/typings](https://www.npmjs.com/package/@moddable/typings)がnpmパッケージとしてModdableのリリースと同期して配信されるようになったため、ビルド時にコピーすることは不要になる想定です。

**あなたが望む解決策**。

`package.json`に `@moddable/typings` パッケージを追加し、`tsconfig.json`をコード管理するようにする。
また、`tsconfig.json`に`mods`や`tests`も含めることでそれらに含まれるファイルからも型定義の補完をできるようにしたいです。

stc1988, 2024-08-17:
現状の[進捗](https://github.com/stc1988/stack-chan/commit/06af7fb3aacc846fe6ed1a3551d8d115712571fe)です

方針としては
* 直接ビルドに使用するものないファイルであり、今後ファイル追加による修正を最小限にすべく、`*`を使って広く対象をマッチさせるようにしています
* `mods`以下などのJSファイルでも補完が効くように`"allowJs": true`としています。

状況としては、
* ビルドは通る([CIのアクション](https://github.com/stc1988/stack-chan/actions/runs/10433230566)は問題なし)
* `npm run lint`も通る
* `npm run generate-apidoc` が失敗する

```
npm run generate-apidoc

> stack-chan@0.2.1 generate-apidoc
> typedoc --entryPointStrategy expand --plugin typedoc-plugin-markdown --out docs/api ./stackchan

Loaded plugin typedoc-plugin-markdown
stackchan/speeches/calculate-power.js:1:33 - error TS1144: '{' or ';' expected.

1 function calculatePower(sample) @ "xs_calculatePower";
                                  ~

stackchan/speeches/calculate-power.js:1:54 - error TS1146: Declaration expected.

1 function calculatePower(sample) @ "xs_calculatePower";

typings/bleserver.d.ts:2:19 - error TS2305: Module '"btutils"' has no exported member 'Advertisement'.

2   import { Bytes, Advertisement } from 'btutils'
                    ~~~~~~~~~~~~~

typings/bleserver.d.ts:3:23 - error TS2792: Cannot find module 'gap'. Did you mean to set the 'moduleResolution' option to 'node', or to add aliases to the 'paths' option?

3   import { GAP } from 'gap'
                        ~~~~~

typings/bleserver.d.ts:149:23 - error TS2792: Cannot find module 'gap'. Did you mean to set the 'moduleResolution' option to 'node', or to add aliases to the 'paths' option?

149   import { GAP } from 'gap'
                          ~~~~~

typings/bleserver.d.ts:203:23 - error TS2792: Cannot find module 'gap'. Did you mean to set the 'moduleResolution' option to 'node', or to add aliases to the 'paths' option?

203   import { GAP } from 'gap'
```
`"allowJs": false`にすると成功します。

@meganetaaan
`bleserver.d.ts`のエラーについては、moddable側の型定義のexportを見直したら解消しますでしょうか。それとも特殊な事象があるでしょうか。

stc1988, 2024-09-19:
メモ：CIでFormatやLintがビルド後に行なっているのはビルド後に`tsconfig.json`が生成されるため。
本件の対応で`tsconfig.json`をgit管理対象とすることでビルド前にFormatやLintを行うことができ、CIで早期に検出可能となる

meganetaaan, 2024-09-19:
確認遅くなりました :pray:

>bleserver.d.tsのエラー

Moddable側の型定義のほうが新しいので、当該ファイルを削除してModdable側を使うことで解消しました。

>npm run generate-apidoc が失敗する

そもそもModdableの独自記法がそのままtscに渡されてSyntax Errorになります。tsconfig.jsonで除外設定を加えることでこちらも解消して、generate-apidocが通るようになりました。

差分を[こちらのブランチ](https://github.com/stack-chan/stack-chan/tree/stc1988-feature/moddable_typings)にpushしてあります。ご確認ください :ok_woman:

stc1988, 2024-09-19:
`@moddable/typings` を5.0.0に上げ、[Lint, Formatをビルド前に実行する](https://github.com/stc1988/stack-chan/actions/runs/10950459489/job/30405719506)こともできました。

差分を見直して今晩にでもPR出します

stc1988, 2024-09-21:
#289 がマージ済みのためクローズします

Closed 2024-09-21.

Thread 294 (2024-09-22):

build flash -firmware

su-cheng-yang, 2024-09-22:
![Uploading F51D9931-E27A-469d-85E8-0EEE00EDB73E.png…]()

su-cheng-yang, 2024-09-22:
please help me

stc1988, 2024-09-23:
Hi, the link you posted is broken and I can't check the details. Could you please repost it?

su-cheng-yang, 2024-09-23:
Hi,Thanks for your reply，This issue is due to computer configuration problems，which have already been solved。I have encountered another problem：

npm run mod ./mods/face/manifest.json
### Error: no manifest!

please help me!

stc1988, 2024-09-23:
Please specify the `target` according to the device you are using, as shown below.

```
npm run mod --target=esp32/m5stack_core2 ./mods/face/manifest.json
```

su-cheng-yang, 2024-09-24:
I followed your instructions to run the command, but still received an error message. However, I changed -- target=esp32/m5stack_core2  to -- target=esp32, and now it can be run.

run as shown below:

s@ubuntu:~/stack-chan/firmware$ npm run mod --target=esp32/m5stack_core2 ./mods/face/manifest.json

> stack-chan@0.2.1 mod
> cross-env npm_config_target?=esp32/m5stack cross-env-shell mcrun -d -m -p $npm_config_target ./mods/face/manifest.json

### Error: No such file or directory
s@ubuntu:~/stack-chan/firmware$ npm run mod --target=esp32 ./mods/face/manifest.json

> stack-chan@0.2.1 mod
> cross-env npm_config_target?=esp32/m5stack cross-env-shell mcrun -d -m -p $npm_config_target ./mods/face/manifest.json

su-cheng-yang, 2024-09-24:
But I encountered another mistake，as shown below:

Python requirements are satisfied.
Please wait - probing for device
Failed to find a suitable device. Check your connections or set UPLOAD_PORT
Please wait - probing for device
Failed to find a suitable device. Check your connections or set UPLOAD_PORT
/bin/sh: 1: [[: not found
/home/s/Projects/moddable/tools/serial2xsbug/serial2xsbug_lin.c:132: No such file or directory
make: *** [/home/s/Projects/moddable/build/tmp/esp32/debug/face/makefile:136: debug] Error 1

However, I have already connected an m5stack.basic to the virtual machine using type_c

stc1988, 2024-09-24:
If you have recently set up the environment with `npm run setup`, it is likely due to an issue with Moddable. In that case, updating Moddable to the latest version
should resolve the issue.

https://github.com/Moddable-OpenSource/moddable/issues/1408

You can check the commit of the installed Moddable with `npm run doctor`.

su-cheng-yang, 2024-09-25:
I'm sorry，Following your advice,updating Moddable to the latest version, reproduced the same problem.as shown below:

Build environment:linux
Target device: esp32/m5stack
Steps to Reproduce:

Build and install the app using this build command: npm run mod --target=esp32/m5stack  ./mods/look_around/manifest.json
/bin/sh: 1: [[: not found
/home/s/Projects/moddable/tools/serial2xsbug/serial2xsbug_lin.c:132: No such file or directory
make: *** [/home/s/Projects/moddable/build/tmp/esp32/debug/look_around/makefile:133: debug] Error 1

stc1988, 2024-09-25:
It's true that there is a failure, but from the logs, it seems that another issue is occurring.

How did you update Moddable?

su-cheng-yang, 2024-09-25:
I will perform the following actions：

git clone https://github.com/Moddable-OpenSource/moddable

su-cheng-yang, 2024-09-27:
I made another attempt，Stuck at the following prompt：

s@ubuntu:~/stack-chan/firmware$ npm run mod --target=esp32/m5stack  ./mods/face/manifest.json
> stack-chan@0.2.1 mod
> cross-env npm_config_target?=esp32/m5stack cross-env-shell mcrun -d -m -p $npm_config_target ./mods/face/manifest.json

Detecting the Python interpreter
Checking "python3" ...
Python 3.8.10
"python3" has been detected
Checking Python compatibility
Using a supported version of tool cmake found in PATH: 3.16.3.
However the recommended version is 3.24.0.
Using a supported version of tool cmake found in PATH: 3.16.3.
However the recommended version is 3.24.0.
Constraint file: /home/s/.espressif/espidf.constraints.v5.3.txt
Requirement files:
 - /home/s/esp32/esp-idf/tools/requirements/requirements.core.txt
Python being checked: /home/s/.espressif/python_env/idf5.3_py3.8_env/bin/python
Python requirements are satisfied.
/bin/sh: 1: [[: not found

Has this open-source project already rejected interested developers  ，please  reply  me ,thank you .

stc1988, 2024-09-27:
As you continue developing stack-chan, I recommend understanding Moddable as well.

For this Moddable update, simply updating the repository is not sufficient. Please refer to the following documentation for the updating and other troubleshooting.

https://github.com/Moddable-OpenSource/moddable/blob/public/documentation/devices/esp32.md

su-cheng-yang, 2024-09-27:
thank you for your reply

Closed 2024-09-27.

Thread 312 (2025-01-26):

Build Failed with Moddable 5.4.0

meganetaaan, 2025-01-26:
**Describe the bug**
A clear and concise description of what the bug is.

**To Reproduce**
Steps to reproduce the behavior:
1. Install Moddable v5.4.0
2. `npm run build`
3. See  errors bellow

```
ble/beacon-packet.ts:54:22 - error TS2693: 'Bytes' only refers to a type, but is being used as a value here.

54     const uuid = new Bytes(payload.slice(2, 18).buffer, true)
                        ~~~~~

ble/beacon-packet.ts:72:16 - error TS2693: 'Bytes' only refers to a type, but is being used as a value here.

72     return new Bytes(this.#payload.slice(2, 18).buffer)
                  ~~~~~
```

stc1988, 2025-01-26:
すみません、　ModdableSDKの[#1452](https://github.com/Moddable-OpenSource/moddable/pull/1452) での対応漏れによるものです。[#1455](https://github.com/Moddable-OpenSource/moddable/pull/1455 で対応をしているので次回ModdableSDK更新に取り込まれる予定です

stc1988, 2025-01-31:
5.4.1がリリースされたので、本リポジトリの定義を取り除いてビルドできるか確認してPR出します

meganetaaan, 2025-02-02:
アップストリームの型定義の干渉が解消されてビルドが通るようになりました。こちらはクローズします🙆

Closed 2025-02-02.

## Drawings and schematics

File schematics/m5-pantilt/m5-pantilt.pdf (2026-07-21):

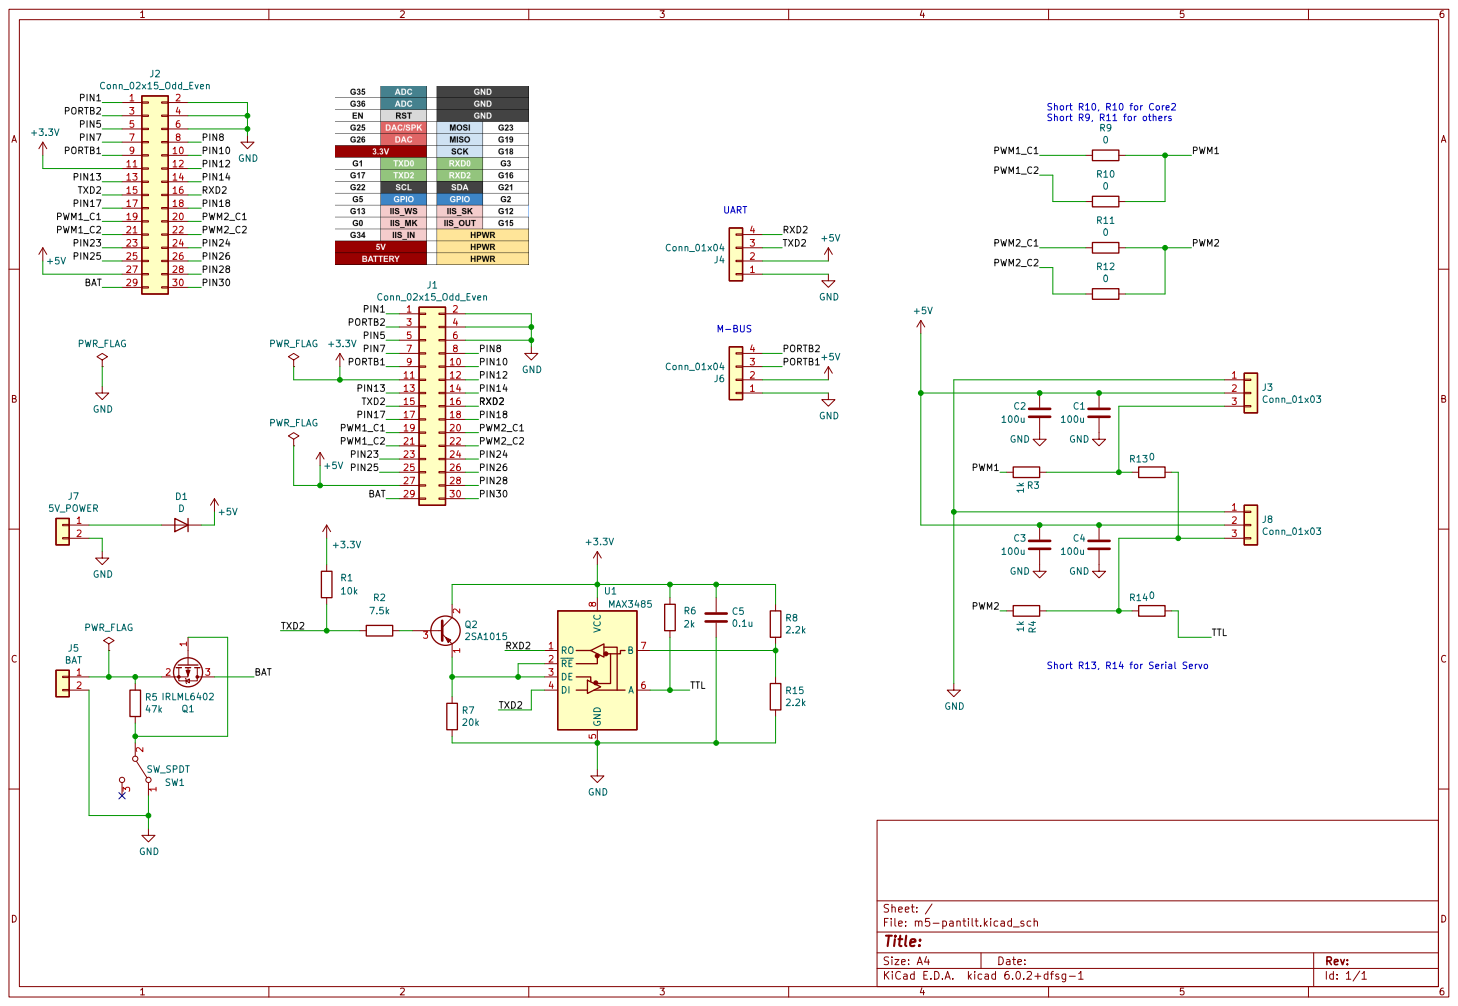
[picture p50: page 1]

Short R10, R10 for Core2 Short R9, R11 for others M-BUS UART

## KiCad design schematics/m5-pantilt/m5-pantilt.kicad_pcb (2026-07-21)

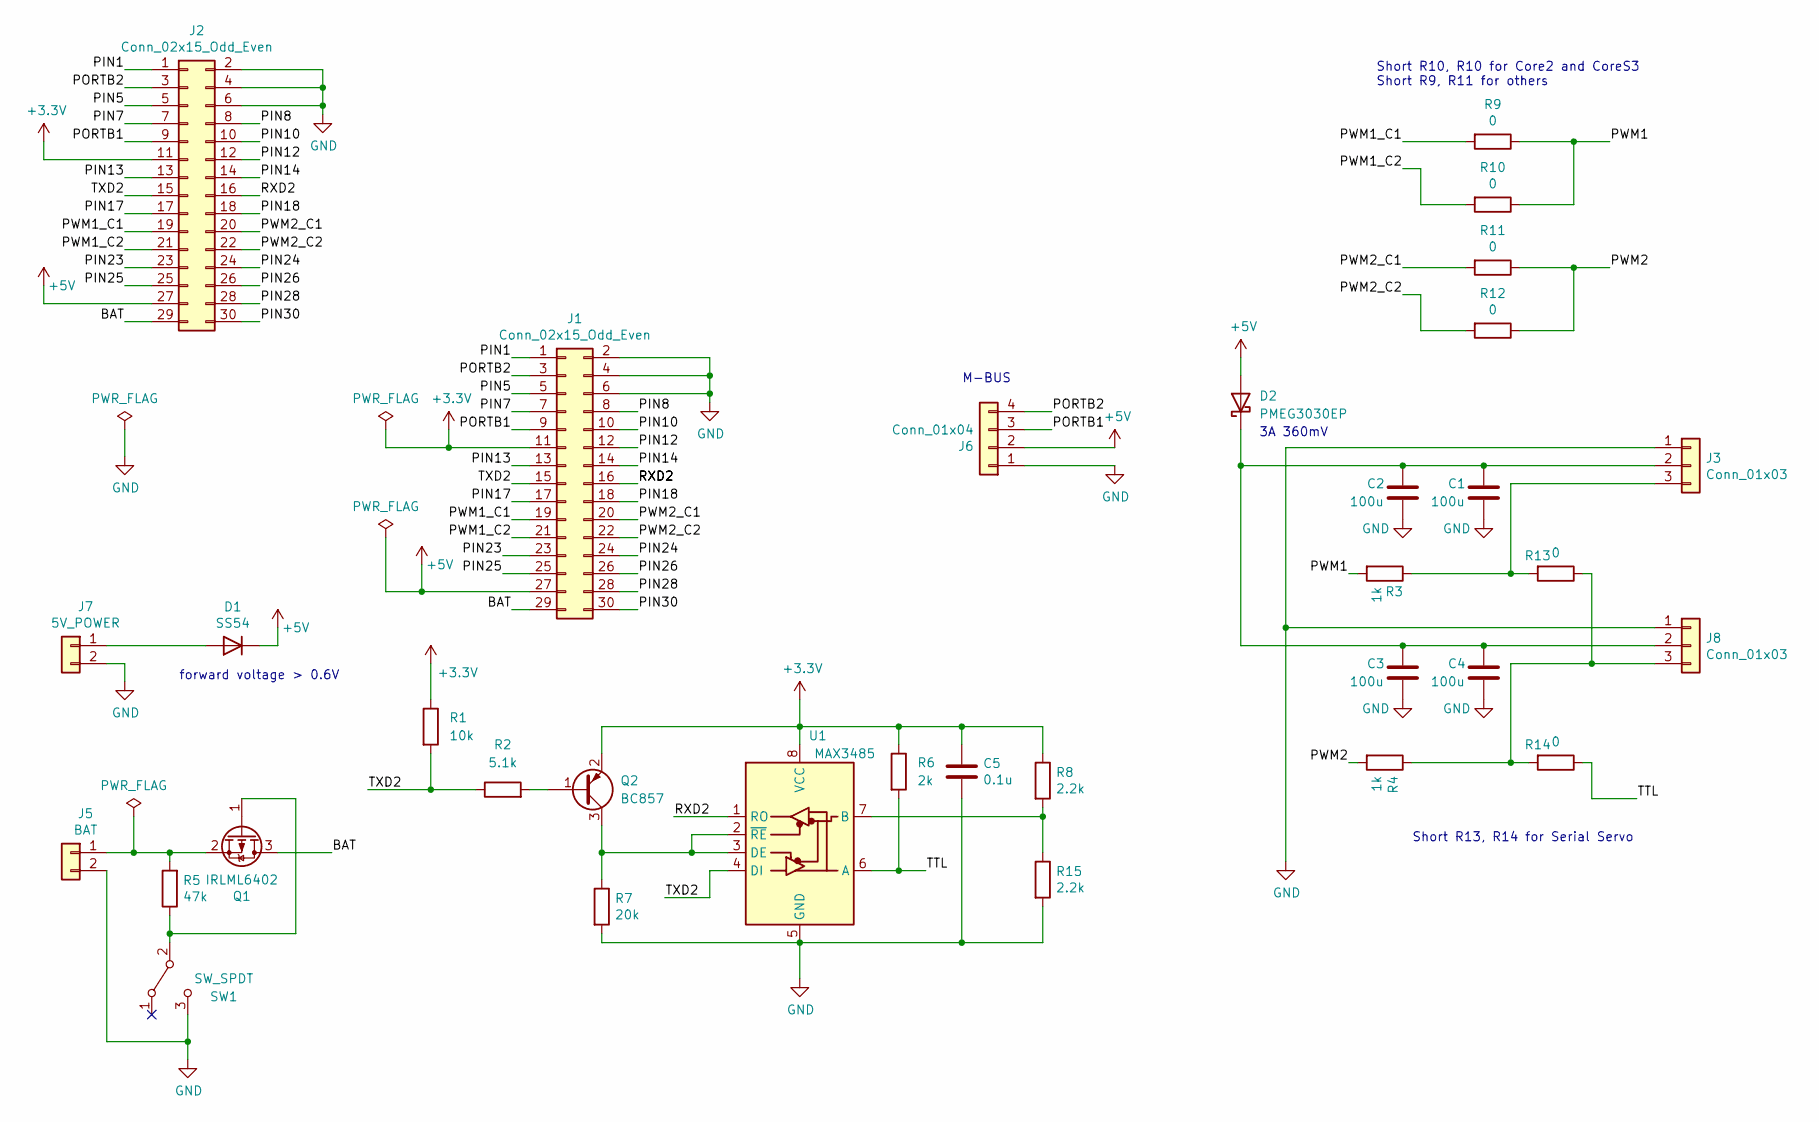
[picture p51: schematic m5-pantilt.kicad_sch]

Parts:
C1, C2, C3, C4: 100u; C_1206_3216Metric_Pad1.33x1.80mm_HandSolder; LCSC C15008
C5: 0.1u; C_0603_1608Metric; LCSC C14663
D1: SS54; D_SMA; LCSC C2931790
D2: PMEG3030EP; D_SOD-128; LCSC C255587
J1: Conn_02x15_Odd_Even; PinHeader_2x15_P2.54mm_Vertical_SMD
J2: Conn_02x15_Odd_Even; PinSocket_2x15_P2.54mm_Vertical_SMD
J3, J8: Conn_01x03; JST_EH_B3B-EH-A_1x03_P2.50mm_Vertical
J5: BAT; JST_PH_B2B-PH-K_1x02_P2.00mm_Vertical; LCSC C2319
J6: Conn_01x04; JST_PH_S4B-PH-K_1x04_P2.00mm_Horizontal
J7: 5V_POWER; JST_XH_B2B-XH-A_1x02_P2.50mm_Vertical; LCSC C20079
Q1: IRLML6402; SOT-23; LCSC C2886430
Q2: BC857; SOT-23; LCSC C2139
R1: 10k; R_0603_1608Metric; LCSC C25804
R2: 5.1k; R_0603_1608Metric; LCSC C23186
R3, R4: 1k; R_0603_1608Metric_Pad0.98x0.95mm_HandSolder; LCSC C21190
R5: 47k; R_0603_1608Metric_Pad0.98x0.95mm_HandSolder; LCSC C25819
R6: 2k; R_0603_1608Metric; LCSC C22975
R7: 20k; R_0603_1608Metric; LCSC C4184
R8, R15: 2.2k; R_0603_1608Metric; LCSC C4190
R9, R10, R11, R12: 0; R_0603_1608Metric_Pad0.98x0.95mm_HandSolder; LCSC C21189
R13, R14: 0; R_0603_1608Metric; LCSC C21189
SW1: SW_SPDT; SW_CuK_OS102011MA1QN1_SPDT_Angled
U1: MAX3485; SO-8_5.3x6.2mm_P1.27mm; LCSC C668204

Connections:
+3V3: C5.1, J1.11, J2.11, Q2.2 (E), R1.1, R6.1, R8.1, U1.8 (VCC)
+5V: D1.1 (K), D2.2 (A), J1.27, J2.27, J6.2
/BAT: J1.29, J2.29, Q1.3 (D)
/PIN1: J1.1, J2.1
/PIN5: J1.5, J2.5
/PIN7: J1.7, J2.7
/PIN8: J1.8, J2.8
/PIN10: J1.10, J2.10
/PIN12: J1.12, J2.12
/PIN13: J1.13, J2.13
/PIN14: J1.14, J2.14
/PIN17: J1.17, J2.17
/PIN18: J1.18, J2.18
/PIN23: J1.23, J2.23
/PIN24: J1.24, J2.24
/PIN25: J1.25, J2.25
/PIN26: J1.26, J2.26
/PIN28: J1.28, J2.28
/PIN30: J1.30, J2.30
/PORTB1: J1.9, J2.9, J6.3
/PORTB2: J1.3, J2.3, J6.4
/PWM1: R3.2, R9.1, R10.1
/PWM1_C1: J1.19, J2.19, R9.2
/PWM1_C2: J1.21, J2.21, R10.2
/PWM2: R4.2, R11.1, R12.1
/PWM2_C1: J1.20, J2.20, R11.2
/PWM2_C2: J1.22, J2.22, R12.2
/RXD2: J1.16, J2.16, U1.1 (RO)
/TTL: R6.2, R14.1, U1.6 (A)
/TXD2: J1.15, J2.15, R1.2, R2.1, U1.4 (DI)
GND: C1.1, C2.1, C3.2, C4.1, C5.2, J1.2, J1.4, J1.6, J2.2, J2.4, J2.6, J3.1, J5.2, J6.1, J7.2, J8.1, R7.2, R15.2, SW1.3 (C), U1.5 (GND)
unnamed: D1.2 (A), J7.1
unnamed: C1.2, C2.2, C3.1, C4.2, D2.1 (K), J3.2, J8.2
unnamed: J3.3, R3.1, R13.2
unnamed: J5.1, Q1.2 (S), R5.2
unnamed: J8.3, R4.1, R13.1, R14.2
unnamed: Q1.1 (G), R5.1, SW1.2 (B)
unnamed: Q2.1 (B), R2.2
unnamed: Q2.3 (C), R7.1, U1.2 (~RE), U1.3 (DE)
unnamed: R8.2, R15.1, U1.7 (B)

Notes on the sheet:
M-BUS
Short R13, R14 for Serial Servo
forward voltage > 0.6V
3A 360mV
Short R10, R10 for Core2 and CoreS3 Short R9, R11 for others

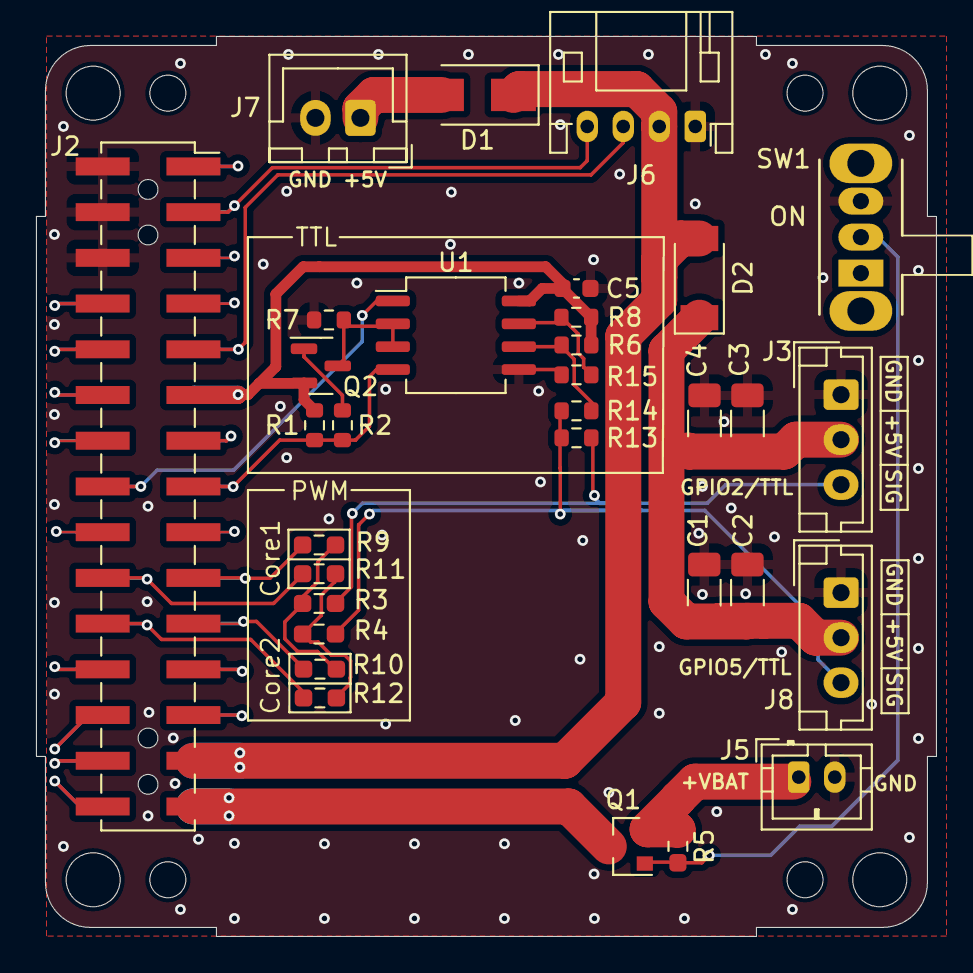
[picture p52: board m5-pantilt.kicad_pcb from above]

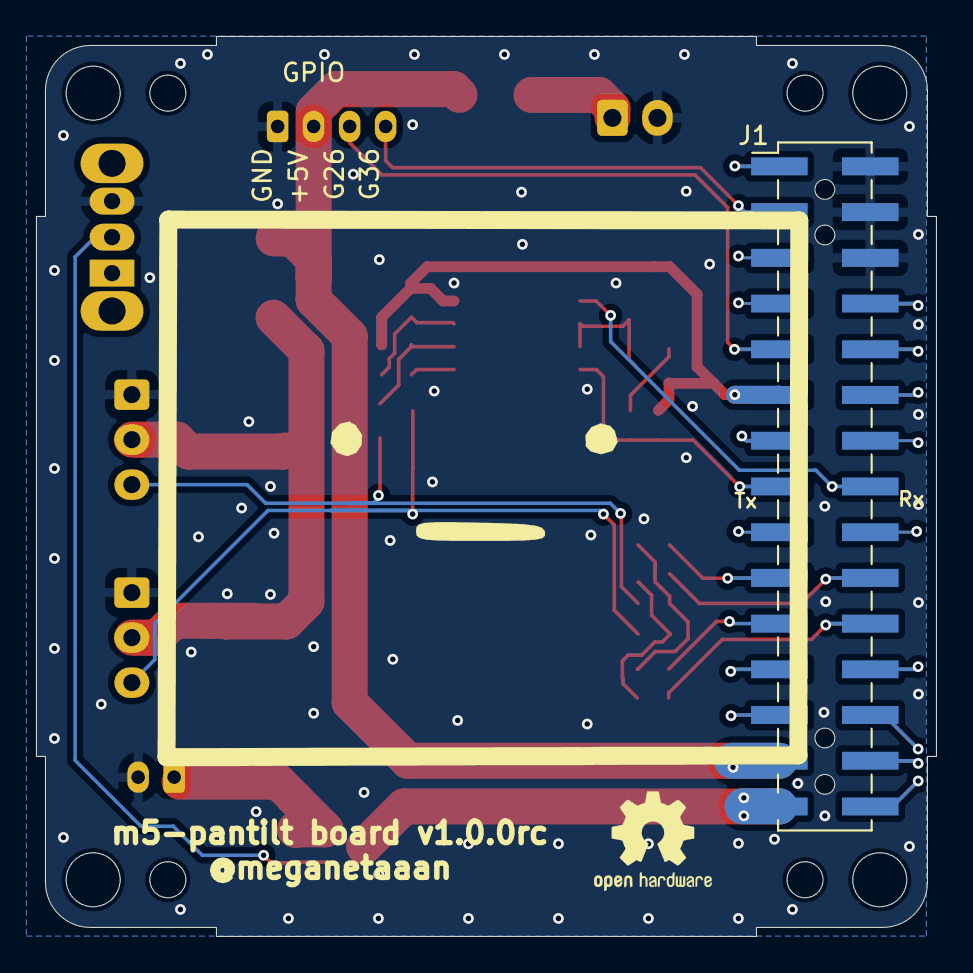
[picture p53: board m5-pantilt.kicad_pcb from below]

Board: 2 copper layers, 50.0 x 50.0 mm, 38 parts (2 on the bottom side), 40 nets.

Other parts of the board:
Hole1, Hole2, Hole3, Hole4: mountinghole_M2_M3
LOGO: LOGO; avatar_small

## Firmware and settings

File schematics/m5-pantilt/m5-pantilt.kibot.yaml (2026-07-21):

# This is a working example.
# For a more complete reference use `--example`
kibot:
  version: 1

global:
  filters:
  - number: 1007
  - number: 1015
  - number: 58
  out_dir: generated

import:
- file: JLCPCB
  definitions:
    _KIBOT_MANF_DIR: Manufacturers/JLCPCB
    _KIBOT_POS_PRE_TRANSFORM: '[''_kicost_rename'', ''_rot_footprint'']'

outputs:
- name: generic_bom_html
  comment: Generic Bill of Materials in HTML format
  type: bom
  dir: BoM/Generic
  options:
    format: HTML
    count_smd_tht: true
- name: generic_bom_xlsx
  comment: Generic Bill of Materials in XLSX format
  type: bom
  dir: BoM/Generic
  options:
    format: XLSX
    count_smd_tht: true
- name: basic_download_datasheets
  comment: Download the datasheets
  type: download_datasheets
  dir: Datasheets
- name: basic_gerb_drill
  comment: Drill files in GERB_DRILL format
  type: gerb_drill
  dir: Gerbers_and_Drill
  options:
    map: gerber
- name: gerber_modern
  comment: Gerbers in modern format, recommended by the standard
  type: gerber
  dir: Gerbers_and_Drill
  layers:
  - layer: F.Cu
    suffix: F_Cu
    description: Front copper
  - layer: B.Cu
    suffix: B_Cu
    description: Bottom copper
  - layer: B.Paste
    suffix: B_Paste
    description: Bottom solder paste
  - layer: F.Paste
    suffix: F_Paste
    description: Front solder paste
  - layer: B.Silkscreen
    suffix: B_Silkscreen
    description: Bottom silkscreen (artwork)
  - layer: F.Silkscreen
    suffix: F_Silkscreen
    description: Front silkscreen (artwork)
  - layer: B.Mask
    suffix: B_Mask
    description: Bottom soldermask (negative)
  - layer: F.Mask
    suffix: F_Mask
    description: Front soldermask (negative)
  - layer: User.Comments
    suffix: User_Comments
    description: User comments
  - layer: User.Eco1
    suffix: User_Eco1
    description: For user usage 1
  - layer: Edge.Cuts
    suffix: Edge_Cuts
    description: Board shape
  - layer: B.Courtyard
    suffix: B_Courtyard
    description: Bottom courtyard area
  - layer: F.Courtyard
    suffix: F_Courtyard
    description: Front courtyard area
  - layer: B.Fab
    suffix: B_Fab
    description: Bottom documentation
  - layer: F.Fab
    suffix: F_Fab
    description: Front documentation
- name: basic_kikit_present
  comment: Simple project presentation
  type: kikit_present
  dir: Presentation
  options:
    description: '# Presentation for m5-pantilt

      This is an automatically generated presentation page'
    boards:
      mode: local
      comment: Resources included
      front_image: renderer_for_present
      back_image: renderer_for_present
      gerbers: gerbers_for_present
- name: renderer_for_present
  comment: Renderer for the presentation
  type: pcbdraw
  dir: Render_for_presentation
  run_by_default: false
- name: gerbers_for_present
  comment: Gerbers for the presentation
  type: gerber
  dir: Gerber_for_presentation
  layers: copper
  run_by_default: false
- name: basic_navigate_results
  comment: Web page to browse the results
  type: navigate_results
  dir: Browse
  options:
    link_from_root: index.html
    skip_not_run: true
- name: basic_pcb_print_pdf
  comment: PCB
  type: pcb_print
  dir: PCB/PDF
  options:
    format: PDF
    pages:
    - layers:
      - layer: F.Cu
      - layer: F.Mask
        color: '#14332440'
      - layer: F.Paste
      - layer: F.Silkscreen
      - layer: Edge.Cuts
      - layer: User.Comments
      - layer: User.Eco1
      sheet: Front copper
    - layers:
      - layer: B.Cu
      - layer: B.Mask
        color: '#14332440'
      - layer: B.Paste
      - layer: B.Silkscreen
      - layer: Edge.Cuts
      - layer: User.Comments
      - layer: User.Eco1
      mirror: true
      sheet: Bottom copper
    - layers:
      - layer: B.Courtyard
      - layer: Edge.Cuts
      - layer: User.Comments
      - layer: User.Eco1
      mirror: true
      sheet: Bottom courtyard area
    - layers:
      - layer: F.Courtyard
      - layer: Edge.Cuts
      - layer: User.Comments
      - layer: User.Eco1
      sheet: Front courtyard area
    - layers:
      - layer: B.Fab
      - layer: Edge.Cuts
      - layer: User.Comments
      - layer: User.Eco1
      mirror: true
      sheet: Bottom documentation
    - layers:
      - layer: F.Fab
      - layer: Edge.Cuts
      - layer: User.Comments
      - layer: User.Eco1
      sheet: Front documentation
    keep_temporal_files: true
- name: basic_pdf
  comment: Individual layers in PDF format
  type: pdf
  dir: Individual_Layers/PDF
  layers:
  - layer: F.Cu
    suffix: F_Cu
    description: Front copper
  - layer: B.Cu
    suffix: B_Cu
    description: Bottom copper
  - layer: B.Paste
    suffix: B_Paste
    description: Bottom solder paste
  - layer: F.Paste
    suffix: F_Paste
    description: Front solder paste
  - layer: B.Silkscreen
    suffix: B_Silkscreen
    description: Bottom silkscreen (artwork)
  - layer: F.Silkscreen
    suffix: F_Silkscreen
    description: Front silkscreen (artwork)
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

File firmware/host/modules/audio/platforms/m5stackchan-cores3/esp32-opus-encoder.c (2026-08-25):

/*
 * Copyright (c) 2026 Shinya Ishikawa
 *
 * Licensed under the Apache License, Version 2.0 (the "License");
 * you may not use this file except in compliance with the License.
 */

#include "xsHost.h"
#include "xsmc.h"
#include "mc.xs.h"

#include "esp_heap_caps.h"
#include "esp_memory_utils.h"
#include "esp_opus_enc.h"
#include "esp_timer.h"
#include "freertos/FreeRTOS.h"
#include "freertos/semphr.h"
#include "freertos/task.h"

#define OPUS_ENCODER_STACK_BYTES (24 * 1024)
#define OPUS_MAX_INPUT_BYTES 1920
#define OPUS_MAX_PACKET_BYTES 1275
#define PCM_FRAME_BYTES 1920
#define PACKET_RING_DEPTH 16
#define PCM_RING_READ 0
#define PCM_RING_WRITE 1
#define PCM_RING_CAPTURED 2
#define PCM_RING_DROPPED_BYTES 3
#define PCM_RING_STATE_WORDS 4

typedef struct {
	uint8_t *data;
	uint32_t *state;
	uint32_t length;
} xsPcmRing;

typedef struct {
	esp_audio_err_t result;
	uint32_t bytes;
	uint32_t generation;
	int64_t elapsed;
	uint8_t data[OPUS_MAX_PACKET_BYTES];
} xsESP32OpusPacket;

typedef struct {
	void *handle;
	uint32_t inputBytes;
	uint32_t outputBytes;
	uint32_t generation;
	uint32_t stop;
	xsPcmRing pcm;
	xsESP32OpusPacket *packets;
	uint32_t packetRead;
	uint32_t packetWrite;
	SemaphoreHandle_t packetSpace;
	SemaphoreHandle_t packetAvail;
	SemaphoreHandle_t pcmGate;
	SemaphoreHandle_t stopped;
	TaskHandle_t task;
} xsESP32OpusEncoderRecord;

static uint32_t pcmRingReadable(const xsPcmRing *ring)
{
	uint32_t read = __atomic_load_n(&ring->state[PCM_RING_READ], __ATOMIC_ACQUIRE);
	uint32_t write = __atomic_load_n(&ring->state[PCM_RING_WRITE], __ATOMIC_ACQUIRE);
	return write >= read ? write - read : ring->length - read + write;
}

static uint32_t pcmRingWritable(const xsPcmRing *ring)
{
	return ring->length - pcmRingReadable(ring) - sizeof(int16_t);
}

static void pcmRingReset(xsPcmRing *ring)
{
	__atomic_store_n(&ring->state[PCM_RING_READ], 0, __ATOMIC_RELEASE);
	__atomic_store_n(&ring->state[PCM_RING_WRITE], 0, __ATOMIC_RELEASE);
	__atomic_store_n(&ring->state[PCM_RING_CAPTURED], 0, __ATOMIC_RELAXED);
	__atomic_store_n(&ring->state[PCM_RING_DROPPED_BYTES], 0, __ATOMIC_RELAXED);
}

static void pcmRingEmpty(xsPcmRing *ring)
{
	uint32_t write = __atomic_load_n(&ring->state[PCM_RING_WRITE], __ATOMIC_ACQUIRE);
	__atomic_store_n(&ring->state[PCM_RING_READ], write, __ATOMIC_RELEASE);
}

static void pcmRingCopyIn(xsPcmRing *ring, const uint8_t *src, uint32_t bytes)
{
	uint32_t write = __atomic_load_n(&ring->state[PCM_RING_WRITE], __ATOMIC_RELAXED);
	uint32_t first = ring->length - write;
	if (first > bytes)
		first = bytes;
	c_memcpy(ring->data + write, src, first);
	if (first < bytes)
		c_memcpy(ring->data, src + first, bytes - first);
	__atomic_store_n(&ring->state[PCM_RING_WRITE], (write + bytes) % ring->length, __ATOMIC_RELEASE);
}

static void pcmRingCopyOut(xsPcmRing *ring, uint8_t *dst, uint32_t bytes)
{
	uint32_t read = __atomic_load_n(&ring->state[PCM_RING_READ], __ATOMIC_RELAXED);
	uint32_t first = ring->length - read;
	if (first > bytes)
		first = bytes;
	c_memcpy(dst, ring->data + read, first);
	if (first < bytes)
		c_memcpy(dst + first, ring->data, bytes - first);
	__atomic_store_n(&ring->state[PCM_RING_READ], (read + bytes) % ring->length, __ATOMIC_RELEASE);
}

static uint32_t pcmRingWriteDownmix(xsPcmRing *ring, const uint8_t *src, uint32_t size, int channels)
{
	uint8_t mono[PCM_FRAME_BYTES];
	uint32_t written = 0;
	const int16_t *input = (const int16_t *)src;
	uint32_t srcSamples;
	uint32_t srcIndex = 0;
	uint32_t outputBytes;

	if (!ring->data || !ring->state || ring->length < (PCM_FRAME_BYTES + sizeof(int16_t)) || !size)
		return 0;
	outputBytes = size / (uint32_t)channels;
	__atomic_add_fetch(&ring->state[PCM_RING_CAPTURED], outputBytes, __ATOMIC_RELAXED);
	if (pcmRingWritable(ring) < outputBytes) {
		__atomic_add_fetch(&ring->state[PCM_RING_DROPPED_BYTES], outputBytes, __ATOMIC_RELAXED);
		return 0;
	}
	srcSamples = size / 2;

	while (srcIndex < srcSamples) {
		uint32_t remain = srcSamples - srcIndex;
		uint32_t chunkSamples = channels == 2 ? remain / 2 : remain;
		uint32_t chunkBytes;
		if (chunkSamples * 2 > sizeof(mono))
			chunkSamples = sizeof(mono) / 2;
		if (!chunkSamples)
			break;
		chunkBytes = chunkSamples * 2;
		if (channels == 2) {
			int16_t *output = (int16_t *)mono;
			uint32_t i;
			for (i = 0; i < chunkSamples; i++)
				output[i] = input[srcIndex + (i * 2)];
			srcIndex += chunkSamples * 2;
		} else {
			c_memcpy(mono, input + srcIndex, chunkBytes);
			srcIndex += chunkSamples;
		}
		pcmRingCopyIn(ring, mono, chunkBytes);
		written += chunkBytes;
	}
	return written;
}

static void opusEncoderTask(void *parameter)
{
	xsESP32OpusEncoderRecord *encoder = parameter;
	uint8_t input[OPUS_MAX_INPUT_BYTES];
	xsESP32OpusPacket output;

	for (;;) {
		uint32_t generation;
		esp_audio_enc_in_frame_t inFrame = {0};
		esp_audio_enc_out_frame_t outFrame = {0};
		int64_t startedAt;
		uint8_t haveFrame = 0;

		if (__atomic_load_n(&encoder->stop, __ATOMIC_ACQUIRE))
			break;

		if (pdTRUE != xSemaphoreTake(encoder->pcmGate, pdMS_TO_TICKS(10))) {
			if (__atomic_load_n(&encoder->stop, __ATOMIC_ACQUIRE))
				break;
			continue;
		}
		if (__atomic_load_n(&encoder->stop, __ATOMIC_ACQUIRE)) {
			xSemaphoreGive(encoder->pcmGate);
			break;
		}
		generation = __atomic_load_n(&encoder->generation, __ATOMIC_ACQUIRE);
		if (encoder->pcm.data && encoder->pcm.state &&
			pcmRingReadable(&encoder->pcm) >= encoder->inputBytes) {
			pcmRingCopyOut(&encoder->pcm, input, encoder->inputBytes);
			haveFrame = 1;
		}
		xSemaphoreGive(encoder->pcmGate);

		if (!haveFrame) {
			vTaskDelay(pdMS_TO_TICKS(20));
			continue;
		}

		inFrame.buffer = input;
		inFrame.len = encoder->inputBytes;
		outFrame.buffer = output.data;
		outFrame.len = sizeof(output.data);
		startedAt = esp_timer_get_time();
		output.result = esp_opus_enc_process(encoder->handle, &inFrame, &outFrame);
		output.elapsed = esp_timer_get_time() - startedAt;
		output.bytes = outFrame.encoded_bytes;
		output.generation = generation;
		if (output.generation != __atomic_load_n(&encoder->generation, __ATOMIC_SEQ_CST))
			continue;

		while (!__atomic_load_n(&encoder->stop, __ATOMIC_ACQUIRE)) {
			if (pdTRUE == xSemaphoreTake(encoder->packetSpace, pdMS_TO_TICKS(10))) {
				encoder->packets[encoder->packetWrite] = output;
				encoder->packetWrite = (encoder->packetWrite + 1) % PACKET_RING_DEPTH;
				xSemaphoreGive(encoder->packetAvail);
				break;
			}
		}
	}
	xSemaphoreGive(encoder->stopped);
	vTaskDelete(NULL);
}

static void drainPackets(xsESP32OpusEncoderRecord *encoder)
{
	while (pdTRUE == xSemaphoreTake(encoder->packetAvail, 0)) {
		encoder->packetRead = (encoder->packetRead + 1) % PACKET_RING_DEPTH;
		xSemaphoreGive(encoder->packetSpace);
	}
}
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

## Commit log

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2022-09-10 Add backpacks
    - casio battery
    - AAA
    [backpack_aaa.step, backpack_aaa.stl, backpack_casio_battery.step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]
2022-09-10 Make slide switch hole wider
    [shell_RS30X.step, shell_RS30X.stl, shell_SCS0009.step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]
2022-09-13 Fix #76 fix pwm pins for silk and doc
    [m5-pantilt.kicad_pcb]
2022-09-15 Update parts position
    [StackChan-BOM_JLCSMT.xlsx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]
2022-09-15 Move assembly files
    [StackChan-BOM_JLCSMT.xlsx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]
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2022-09-18 Add bottom hole for backpack AAA
    [backpack_aaa.step, backpack_aaa.stl]
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2023-01-07 Expand mod partition
    [customPartitions.csv]
2023-01-07 Fix calibration
    Still under construction
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2023-01-08 Remove comments
    [customPartitions.csv]
2023-01-09 Fix props for PWMDriver
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2023-01-09 Fix PWMDriver according to current API
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2023-01-24 Workaround to avoid exception on startup
    ```
    # Exception: WeakMap.prototype.set: WeakMap instance is read-only!
    ```
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2023-03-14 HS Glide PathさんのSTLファイルをアップロード
    [shell_SG90_AWS_LED.stl, spacer_for_AWS.stl]
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2023-03-14 画像修正02
2023-03-14 画像修正03
2023-03-14 画像修正04
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2023-03-16 英語README.mdの追加、日本語README.mdの修正
2023-03-18 Update bracket_SG90 and step files
    [bracket_SG90.step, bracket_SG90.stl, bracket_SG90_v1.1.stl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]
2023-03-20 #139の暫定対応として記述を修正いたしました。 問題なければ取り込んでいただけますと幸いです。 ご指摘等ありましたらご連絡ください。
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2023-03-24 Contributed shell model and document has been added.
    [shell_SG90_magnet_latch.step, shell_SG90_magnet_latch.stl]
2023-03-29 Review file names and folder structure
    [bracket_MG90S_v1.0.stl, feet_SG90_v1.0.stl, feet_SG90_v1.0.stp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]
2023-04-17 Change samplerate for tts-voicevox
    A workaround for https://github.com/meganetaaan/stack-chan/issues/156
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2023-04-21 add bracket_SG90_v2.0.stl
    [bracket_SG90_v2.0.stl]
2023-05-10 Shell model for Tamiya universal metal joint parts
    [shell_SG90_magnet_latch_plate.stl]
2023-05-15 Adding AWS support shell model and documents.
    [shell_SG90_magnet_latch.step, shell_SG90_magnet_latch.stl]
2023-05-15 Delete shell_SG90_magnet_latch_Core2_AWS.stl
    Move to Core2/AWS common design shell.
    [shell_SG90_magnet_latch_Core2_AWS.stl]
2023-05-20 ElevenLabs TTS
    [customPartitions.csv]
2023-06-03 Fix jlcpcb part number
    [StackChan-BOM_JLCSMT.xlsx]
2023-06-03 xlsx -> csv
    [StackChan-BOM_JLCSMT.csv, StackChan-BOM_JLCSMT.xlsx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]
2023-06-03 Use 1k resistors
    [StackChan-BOM_JLCSMT.csv]
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2023-07-20 WIP: new board
    [m5-pantilt.sch]
2023-07-24 Fix keys according to current pref impl
2023-08-07 WIP: board update
    [m5-pantilt.kicad_pcb, m5-pantilt.kicad_sch]
2023-08-08 WIP: Refine board
    [m5-pantilt.kicad_pcb, m5-pantilt.kicad_sch]
2023-08-08 WIP: update board
    [m5-pantilt.kicad_pcb, m5-pantilt.kicad_sch]
2023-08-08 Generate gerber
    [m5-pantilt-B_Cu.gbl, m5-pantilt-B_Mask.gbs, m5-pantilt-B_Paste.gbp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]
2023-08-08 Update board
    [m5-pantilt-B_Cu.gbl, m5-pantilt-B_Mask.gbs, m5-pantilt-B_Paste.gbp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]
2023-08-09 Remove old files
    [m5-pantilt.sch]
2023-08-09 Upgrade to KiCad 7
    [m5-pantilt.kicad_pcb, m5-pantilt.kicad_sch]
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2023-08-09 Specify forward voltage of the diode
    [m5-pantilt.kicad_sch]
2023-08-09 Add LCSC part number
    [m5-pantilt.kicad_pcb, m5-pantilt.kicad_sch]
2023-08-10 WIP: Add v2 cases
    [bracket_XL330_b.step, bracket_XL330_b.stl, bracket_XL330_f.step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]
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2023-08-15 Fix switch hole
    [shell.step, shell.stl]
2023-08-15 Add narrow hole gear
    [gear_XL330_narrow.step, gear_XL330_narrow.stl]
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2023-09-01 fix install button selector
2023-09-05 Fix #198 Offset servo angle (180 degree)
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2023-09-09 add magnet type shell for M5Stack Basic v2.7
    [shell_SG90_magnet_basic_v2.7.step, shell_SG90_magnet_basic_v2.7.stl]
2023-09-14 Improve power function of the board
    [m5-pantilt.kicad_pcb, m5-pantilt.kicad_sch]
2023-09-14 Remove gerber and other production files
    They should be auto-generated through CI
    [StackChan-BOM_JLCSMT.csv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]
2023-09-14 Fix silk
    [m5-pantilt.kicad_pcb]
2023-09-14 Add OSHW logo
    [m5-pantilt.kicad_pcb]
2023-09-15 Avoid interference with shell by miniaturizing battery case
    [backpack_640mah.step, backpack_640mah.stl]
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2023-09-19 Adjust clearance
    [feet_top.step, feet_top.stl, horn.step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]
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2023-09-29 v2 -> v1
    [bracket_XL330_b.step, bracket_XL330_b.stl, bracket_XL330_f.step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]
2023-11-17 Update README.md
    The image extension was incorrect and was not displayed, so I fixed it. jpg to png
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2024-09-03 fix sampleRate of tests/speeches/tts-voicevox
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2024-10-20 Fix the offset incrementation to account for bytes per sample
2026-05-10 Deploy schematics files from 275ba240e42db88f8225c2ff749d4848693ff1b5
    [m5-pantilt-3D.step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]
2026-05-11 Deploy schematics files from d79e0f873e85952ff812330441ddca656c4250d4
    [m5-pantilt-3D.step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]
2026-05-11 Deploy schematics files from 0c59d71163bd04338b3e110fcc787097c1422835
    [m5-pantilt-3D.step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]
2026-05-15 Deploy firmware bundle from c9b1425dc572fb75194e84e9fe63a2f67fd41f1d
    [shell.stl]
2026-06-07 Deploy schematics files from a68560bdfecd82e907cff168c08364f63e5e56bb
    [m5-pantilt-3D.step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]
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2026-06-24 Deploy schematics files from 276f479184d37b23bb7b6844438d0f6cf07b7473
    [m5-pantilt-3D.step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]
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2026-07-07 [codex] Firmware rearchitecture migration (#497)
    * docs: add firmware rearchitecture migration plan
    * firmware: add legacy migration guard
    * firmware: move piu implementation into ui
    * Remove legacy renderer compatibility layer
    * docs: add legacy migration review gate
    * firmware: move ui module under host modules
    * firmware: move settings view into ui module
    * firmware: replace face context with face state
    * firmware: avoid per-frame face coordinate reassignment
    * firmware: render emoticons through piu port
    * firmware: render standard face parts through piu port
    * firmware: render dog face parts through piu port
    * firmware: cache bubble drawing resources
    * firmware: move app ent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
2026-07-07 fix(ci): build the intended targets in the firmware build matrix (#504)
    The m5stack / m5stack_cores3 legs used `npm run build --target=...`,
    but npm turns `--target` into the npm_config_target env var, which
    scripts/firmware.mjs never reads. Both legs silently fell back to the
    default m5stackchan_cores3 device, so the plain m5stack targets were
    never actually built in CI.
    - Add build:m5stack / build:m5stack_cores3 scripts that call mcconfig
    directly, matching the pre-rearchitecture build behavior
    - Point the CI matrix at the named scripts and add the missing
    takao_core2_sg90 leg
    - Make firmware.mjs fail loudly when npm_config_target is set instead
    of silently building the default devi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
2026-07-07 fix(lifecycle): complete context close + move migration scratch notes (#508)
    * fix(lifecycle): release audio and lighting resources on context close
    StackchanContext.lifecycle.close() promises to release resources owned
    by the runtime context but only handled motion, camera, and input.
    Close now also stops the microphone, detaches the TTS playback
    callbacks, and turns off every LED. Connectivity stays open because it
    is owned by boot-services, not the context.
    The wasm Microphone gains a stop() alias for close() so both device
    and wasm implementations satisfy the same contract.
    * chore: move migration scratch notes into firmware/docs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
2026-07-09 fix(motion): verify CRC of received Dynamixel status packets (#531)
    The Dynamixel protocol 2.0 CRC-16 was only used when generating
    transmit packets; received status packets were accepted without
    verification, so a packet corrupted on a noisy serial line (e.g.
    present position) could feed wrong values into motion control.
    Move the CRC-16 into dynamixel-codec so it is unit-testable, use it
    for both transmit generation and receive verification, and discard
    packets whose trailing CRC does not match. A discarded packet lets
    the pending command time out, which surfaces a CommandTimeoutError
    through the existing command queue recovery path, mirroring how the
    SCServo driver already handles checksu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
2026-07-11 feat(web): Blockly MOD editor with in-browser build and install (#538)
    * feat(web): Blockly MOD editor with in-browser build and device flashing
    Add web/editor, a Blockly-based Stack-chan MOD editor that runs entirely
    client-side:
    - Compose Stack-chan behaviors (face, speech, motion, LED, buttons,
    timers) from blocks; the workspace generates a mod.js exporting
    onContextCreated(robot).
    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
2026-07-11 feat(firmware): add manifest preflight check (check:manifest) (#516)
    * chore: move migration scratch notes into firmware/docs
    tasks.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
2026-07-11 Codex/frontend guidance UI (#540)
    tasks.md was a stale ChatGPT tool-call ta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
2026-07-12 test: overhaul firmware test infrastructure (parallel runner, tautology removal, xs unification, device smoke) (#543)
    * perf(test): run Moddable module tests incrementally and in parallel
    Stop deleting build output before every run (mcconfig regenerates the
    makefile each invocation and mc.xs.c depends on the manifest include
    chain, so incremental builds are safe; STACKCHAN_MODULE_TEST_CLEAN=1
    restores clean builds) and run tests through a worker pool
    (STACKCHAN_MODULE_TEST_JOBS, default min(4, cores)).
    Parallel mcsim instances need two isolations: a private DBus session per
    test (mcsim is a fixed-application-id GtkApplication, so a second
    instance on the same bus hands off to the first and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
    [ft6206_async_m5stackchan.js]
2026-07-14 feat(firmware): add selectable CoreS3 WebRadio (#553)
    * feat(audio): add CoreS3 web radio runtime
    * feat(ui): add relaxed face and music notes
    * feat(mod): add WebRadio example
    * fix(app): instantiate WebRadio module constructor
    * fix(audio): stabilize CoreS3 WebRadio streaming
    * perf(ui): simplify WebRadio playback effects
    * test(firmware): add WebRadio device diagnostics
    * refactor(audio): remove inactive WebRadio paths
    * feat(mod): add WebRadio stations and note fade
    * feat(ui): show WebRadio connection indicator
    * fix(ci): move WebRadio diagnostics under audio module
    * fix(firmware): address WebRadio review feedback
    * refactor(web-radio): align release volume and UI checks
    *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
    [esp32-mp3-decoder.c]
2026-07-16 feat: complete Phase 4 visual programming (#555)
    * feat: complete Phase 4 visual programming
    * chore: record visual programming validation
    * test: stabilize visual programming browser checks
    * docs: update visual programming test count
    * test: preserve simulator screen evidence
    * ci: verify editor tools before deployment
    * test: enforce first-run metrics gate
    * test: cover metrics aggregation workflow
    * test: audit accessible control names
    * test: cover static workspace diagnostics
    * test: guard visual block security surface
    * docs: record visual programming acceptance audit
    * fix: keep simulator sample compatible
    * docs: record CoreS3 visual programming smoke
    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
2026-07-17 feat(audio): add offline stackchan-voice speech and singing (#541)
    * feat(audio): add streaming stackchan voice TTS
    * feat(default): add speech synthesis drawer action
    * fix(audio): use async streaming output
    * fix(audio): drain async output before closing
    * fix(audio): finish after DMA playback drains
    * fix(audio): align streaming chunks to DMA
    * chore(audio): sync stackchan-voice snapshot
    * fix(audio): scope stackchan-voice to CoreS3
    * fix(audio): provide AudioOut on Linux
    * fix(audio): address stackchan voice review
    * feat(audio): enable stackchan voice in wasm simulator
    * fix(audio): write stackchan voice as byte view
    * fix(audio): bound stackchan voice rendering
    * chore: ad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
2026-07-19 feat: add abstract local peer communication (#561)
    * feat: add abstract local peer communication
    * fix: prevent local peer timeout restarts
    * fix: address local peer review feedback
    * fix: preserve errexit in Linux smoke test
    * fix: authenticate secure local peer frames
    * fix: keep local peer within firmware limits
    * feat: add automatic local peer demo roles
    * feat: select local peer role from drawer
2026-07-19 fix: enforce platform-specific servo driver settings (#569)
    * fix: enforce platform servo driver settings
    * fix: address preference review feedback
2026-07-19 fix: normalize UI display list capacity (#570)
2026-07-20 fix: use head LED in block sample (#572)
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2026-07-20 feat: add mini app framework (#562)
    * feat: add mini app framework
    * test: add mini app Linux smoke
    * fix: address mini app review feedback
    * style: satisfy biome import ordering
    * test: add mini app registry to drawer UI stub
    * ui: reveal AppBar actions before opening drawer
    * feat: turn mini app sample into jump game
    * fix: address mini app review feedback
    * set status indicator inactive to avoid capturing
2026-07-20 feat(i18n): Webとfirmwareを日本語・英語・簡体中国語に対応 (#563)
    * feat(i18n): localize web and firmware
    * fix(i18n): address CI and review feedback
    * test(i18n): tighten localization contracts
    * fix(i18n): reduce localized font bundle size
    * feat(i18n): expose localization to mods
    * fix(i18n): address MOD capability review
    * docs(i18n): label locale catalog examples
    * test(web): wait for editor state restoration
2026-07-21 fix(firmware): stabilize CoreS3 camera DMA
2026-07-21 fix: correlate USB audio sessions
    [usb-audio-diagnostics.py]
2026-07-21 fix: harden USB speaker receive flow
2026-07-22 fix: clarify web device setup prerequisites
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2026-07-24 fix(web): update ESP32-S3 WebSerial transport
2026-07-26 fix(firmware): address Android USB audio review
    [test_usb_audio_diagnostics.py, usb-audio-diagnostics.py]
2026-07-26 fix(firmware): validate diagnostic trace schema
    [test_usb_audio_diagnostics.py, usb-audio-diagnostics.py]
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2026-07-28 fix(firmware): pause hidden app bar status timers
2026-07-28 fix(wasm): await browser camera restart
2026-07-29 fix(ui): restore CoreS3 battery status
2026-07-31 docs: fix ESP32 setup and command examples
2026-08-02 fix: separate spinner frames from icon size
2026-08-09 chore(deps): bump blockly from 13.1.1 to 13.2.0 in /web (#628)
    Bumps [blockly](https://github.com/RaspberryPiFoundation/blockly) from 13.1.1 to 13.2.0.
    - [Release notes](https://github.com/RaspberryPiFoundation/blockly/releases)
    - [Commits](https://github.com/RaspberryPiFoundation/blockly/compare/blockly-v13.1.1...blockly-v13.2.0)
    ---
    updated-dependencies:
    - dependency-name: blockly
    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
2026-08-11 feat: add a mini-app UI playground (#647)
    * feat: add a mini-app UI playground
    * chore: sort mini-app test imports
    * fix: keep mini-app notice clear of controls
    * fix: preserve mini-app close button size
    * fix: publish UI playground in MOD Gallery
2026-08-14 feat(firmware): select MODs from SD card (#656)
    * feat(firmware): select MODs from SD card
    * fix(firmware): preserve MOD launch ownership
    * fix(firmware): support ESP-IDF SD header move
    * fix(firmware): address MOD selector review
    * fix(firmware): keep MOD selector reachable
    * fix(firmware): isolate MOD manager from platform
    * fix(firmware): preserve MOD recovery access
    * fix(firmware): recover from invalid MOD startup
    [sd-card.c]
2026-08-18 fix(chat): make XiaoZhi sessions reconnectable
    [xiaozhi-model.js]
2026-08-18 fix(chat): address XiaoZhi review feedback
    [xiaozhi-model.js]
2026-08-18 test(audio): harden Opus device fixture
2026-08-18 fix(chat): address full XiaoZhi review
    [xiaozhi-model.js]
2026-08-18 fix(test): keep device fixture out of simulator suite
2026-08-18 fix(chat): restore ESP32 audio worker mappings
2026-08-18 fix(test): isolate device-only Opus fixture
2026-08-18 fix: encode XiaoZhi Opus asynchronously
    [esp32-opus-encoder.c, xiaozhi-model.js]
2026-08-18 fix: discard stale Opus encoder packets
    [esp32-opus-encoder.c]
2026-08-18 fix: exclude fallback audio module on devices
2026-08-18 Stabilize XiaoZhi audio scheduling
    [esp32-opus-encoder.c]
2026-08-18 fix(chat): ship the XiaoZhi contract inside the worker graph
    The XiaoZhi worker imported a parent-directory TypeScript module that
    never entered the device module table, so ChatService failed before
    opening the realtime socket.
    [xiaozhi-model.js]
2026-08-18 fix(chat): pass XiaoZhi biome and Moddable type checks
    Biome ci failed on import order and Object.hasOwn.
    Moddable tsc rejected untyped configuration access
    and the stale xiaozhiV1Contract module specifier.
    [xiaozhi-model.js]
2026-08-20 fix(chat): stabilize XiaoZhi audio ownership
    [esp32-opus-encoder.c, xiaozhi-model.js]
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2026-09-06 fix: preload CoreS3 power capture for standalone applications
2026-09-30 fix(motion): clamp M5StackChan pitch to recommended range
2026-09-30 fix(ble): keep Settings usable when write timer allocation fails
2026-10-04 test(audio): explicitly replace the SDK timer in clean builds
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2026-10-08 fix(ui): let the Wi-Fi password screen confirm from the header
    The password screen had no confirm control of its own and relied on the OK
    key of the Moddable expanding keyboard. That key does not submit while the
    key rows are expanded: KeyboardBehavior.onKeyUp turns Enter into another row
    transition instead of passing it to the field, so on the device the password
    could not be entered at all.
    The header now carries a check action that delegates Enter straight to the
    KeyboardField. KeyboardFieldBehavior.onKeyUp distributes onKeyboardOK from
    there, so the existing submit path runs unchanged and only the broken entry
    point is bypassed. ScreenHeader gains 'check' as a trailing icon; the icon
    it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
2026-10-08 test(mods): record paired native avatar device measurements
    [cores3-native-20261008.csv]
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2026-10-08 fix(test): name native avatar asynchronous timer sequence
2026-10-08 perf(avatar-dsl): reduce native geometry copies and batch CoreS3 raster bands
    [cores3-loop-20261009.csv]
2026-10-08 fix(ble): enforce elapsed write deadline before saving
    Check Time.ticks/Time.delta at RX and before each preference save so delayed timer dispatch cannot admit expired requests. Preserve timer cleanup, the five-minute duration and read-only behavior.
    Cover tick rollover, batch/parse/storage-read delays, fragmented messages, reconnect and Settings lifecycle. Validate with 445 unit tests, two XS manifests including native delayed dispatch, 78 architecture tests and six target manifest preflights.
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2026-10-10 fix: poll decoded xsdb logs in device smoke
2026-10-11 Fix runner teardown and retain late failure precedence
    Escalate owned process groups from TERM to KILL and wait for pipe closure.
    Recheck failures received while stopping after PASS. Exercise normal runner
    async completion, abnormal exits, failed warmup cleanup and resistant children.
2026-10-14 fix: allow PY32 LED count setup to settle before RGB writes
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2026-10-17 fix(build): seed RT camera dependencies before make
    Prepare camera and JPEG dependencies in the RT output directory before mcconfig
    and restore them after variant cleanup. This avoids concurrent SDK add-dependency
    updates dropping entries from idf_component.yml on clean release builds.
    Cover RT output modes, idempotence, and clean/incremental/manifest-switch flows.
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2026-10-20 fix: restore MediaPipe Gallery archive entry module
    Release impact: patch. Rebuild MediaPipe with SDK 10.0.2 from a clean output directory, version the artifact URL, and prevent sharing the Codex Voice entry bytecode. Firmware source and device state are unchanged.
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2026-10-24 fix(ci): pin SDK runners and patch web audit dependencies
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2026-11-05 fix(build): clean direct CoreS3 manifest switches
2026-11-13 fix: adopt Moddable SDK 10.1.1 network fixes (#802)
    SDKと型定義、CI・Docker・WASMの指定をModdable 10.1.1へ統一し、ブラウザーMODコンパイラーを再生成する。
    fetchと本文読み出しの通信失敗、次回対話の復帰、接続再利用、redirect、空POST/PUTの回帰テストを追加し、移行手順と互換性検証を更新する。
